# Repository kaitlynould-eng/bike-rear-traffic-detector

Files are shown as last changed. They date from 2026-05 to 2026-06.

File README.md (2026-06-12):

# bike-rear-traffic-detector

https://kaitlynould-eng.github.io/bike-rear-traffic-detector/

## Background

The purpose of this project is to assist a member of the team’s mom, Paula Ould. Paula was suddenly diagnosed in 2022 with a benign but hemorrhaging brain tumor. The tumor has since been successfully removed, but the process has limited her eyesight and degraded her motor function, rendering her legally unable to drive.
Since the surgeries, she has purchased an e-trike from RadPower to safely travel short distances from her house. She has added a mirror to increase her field of vision and a flag for visibility, among other modifications. She is able to ride safely in low-traffic environments, but is still nervous about biking on busier roads or at busier times of day because it is harder for her to detect objects at the very edge of her peripherals or behind her.
Therefore, our team’s goal is to create a system that detects and communicates the presence of rear oncoming traffic to Paula while she is on the road. This system is intended to act as an additional layer of information to support her existing safety measures, helping improve awareness and confidence, rather than encouraging riding in higher-risk conditions.

<div align="center">
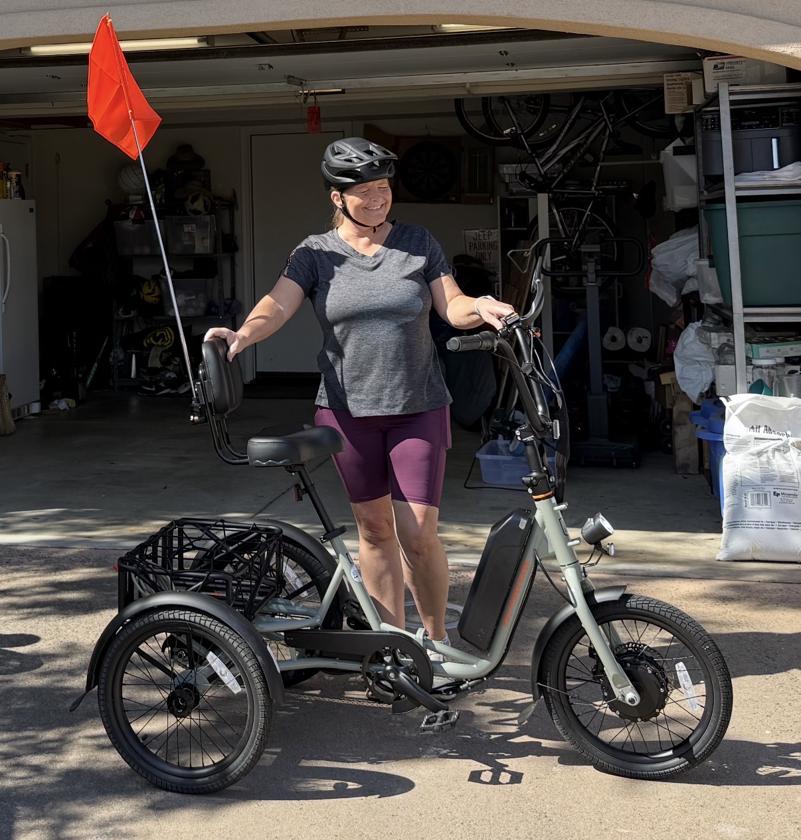
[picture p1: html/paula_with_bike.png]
    
    <br>
    <b>Figure 1:</b> User with RadPower E-trike.
</div>

## Introduction

Rear-facing bicycle safety and rider awareness system using mmWave radar, an STM32F411, and directional haptic feedback. Detects nearby vehicles in real time and alerts the rider through handlebar vibration motors using onboard radar and IMU sensor fusion.

# Hardware Design

## Overview

<div align="center">
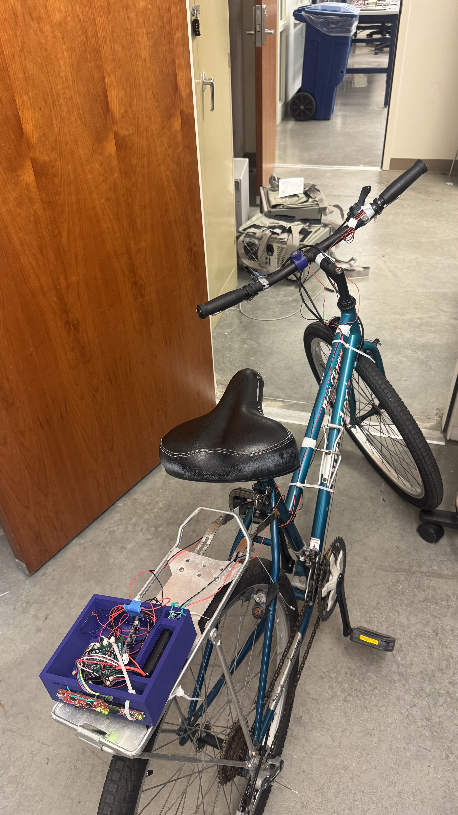
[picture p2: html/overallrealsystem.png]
    
    <br>
    <b>Figure 2:</b> Full prototype.
</div>

The hardware architecture of the rider-awareness system is centered around a custom printed circuit board that integrates sensing, processing, power regulation, and haptic feedback subsystems into a compact assembly suitable for bicycle use. The system is powered by a 2-cell lithium-ion battery pack and is designed to operate reliably in a vibration-prone outdoor environment through the use of connectorized wiring harnesses, regulated power distribution, and mechanically secured components.

A rear-facing TI IWR6843 mmWave radar module serves as the primary sensing device for detecting approaching vehicles and other rear hazards. An onboard BNO055 inertial measurement unit (IMU) provides orientation and motion data that allow the system to distinguish between riding and stationary conditions. Sensor data is processed by an STM32F411 microcontroller, which coordinates system operation and controls the rider notification subsystem.

Rider alerts are communicated through two handlebar-mounted vibration motors driven by dedicated DRV2605L haptic motor driver ICs. This haptic feedback approach was selected to provide intuitive notifications without requiring the rider to divert visual attention from the road or rely on audible alerts that may be masked by environmental noise.

All electronic components except for the motors are housed within a custom 3D-printed enclosure mounted to the rear cargo rack of a substitute bicycle. Paula’s e-trike was unavailable during testing, and so the prototype enclosure will be updated in the future to match the geometry of the intended vehicle. The enclosure incorporates dedicated mounting features and attachment points to securely retain the PCB, battery, radar module, and associated wiring. During prototype testing, the enclosure was secured to a substitute bicycle using zip ties attached to a rear basket rack, providing a simple and robust mounting solution without requiring permanent modifications to the bicycle. Internal cable management and connectorized harnesses were used to minimize strain on electrical connections and improve serviceability. Motors were mounted to the bike by being pressed into small, ring-like fixtures that snapped onto each handlebar.

<div align="center">
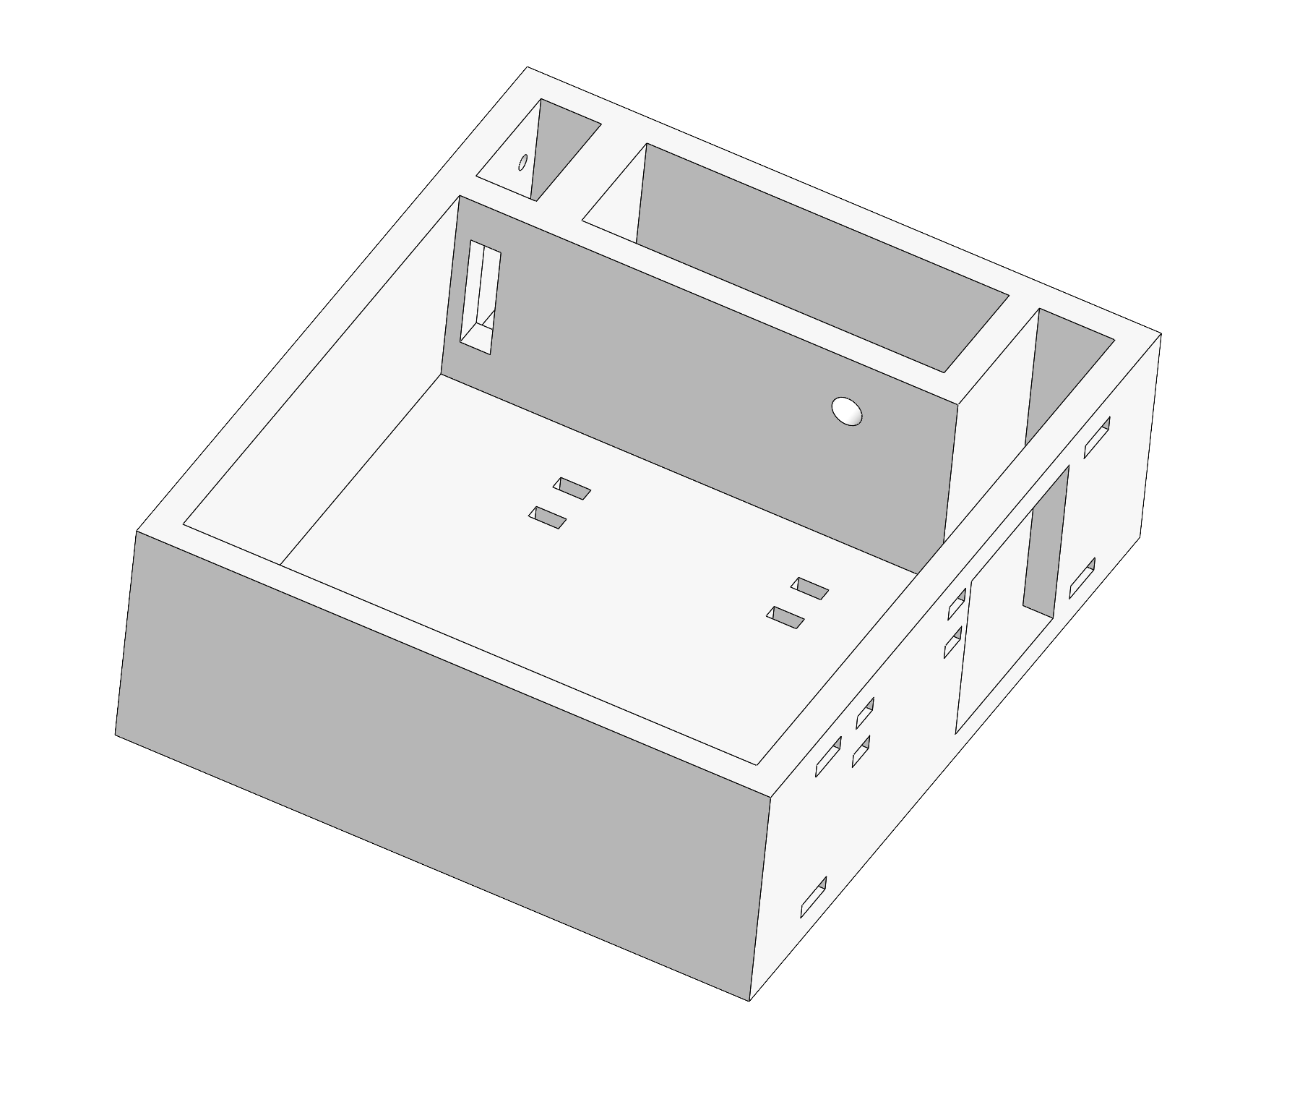
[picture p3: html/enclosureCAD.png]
    
    <br>
    <b>Figure 3:</b> Enclosure design.
</div>
<div align="center">
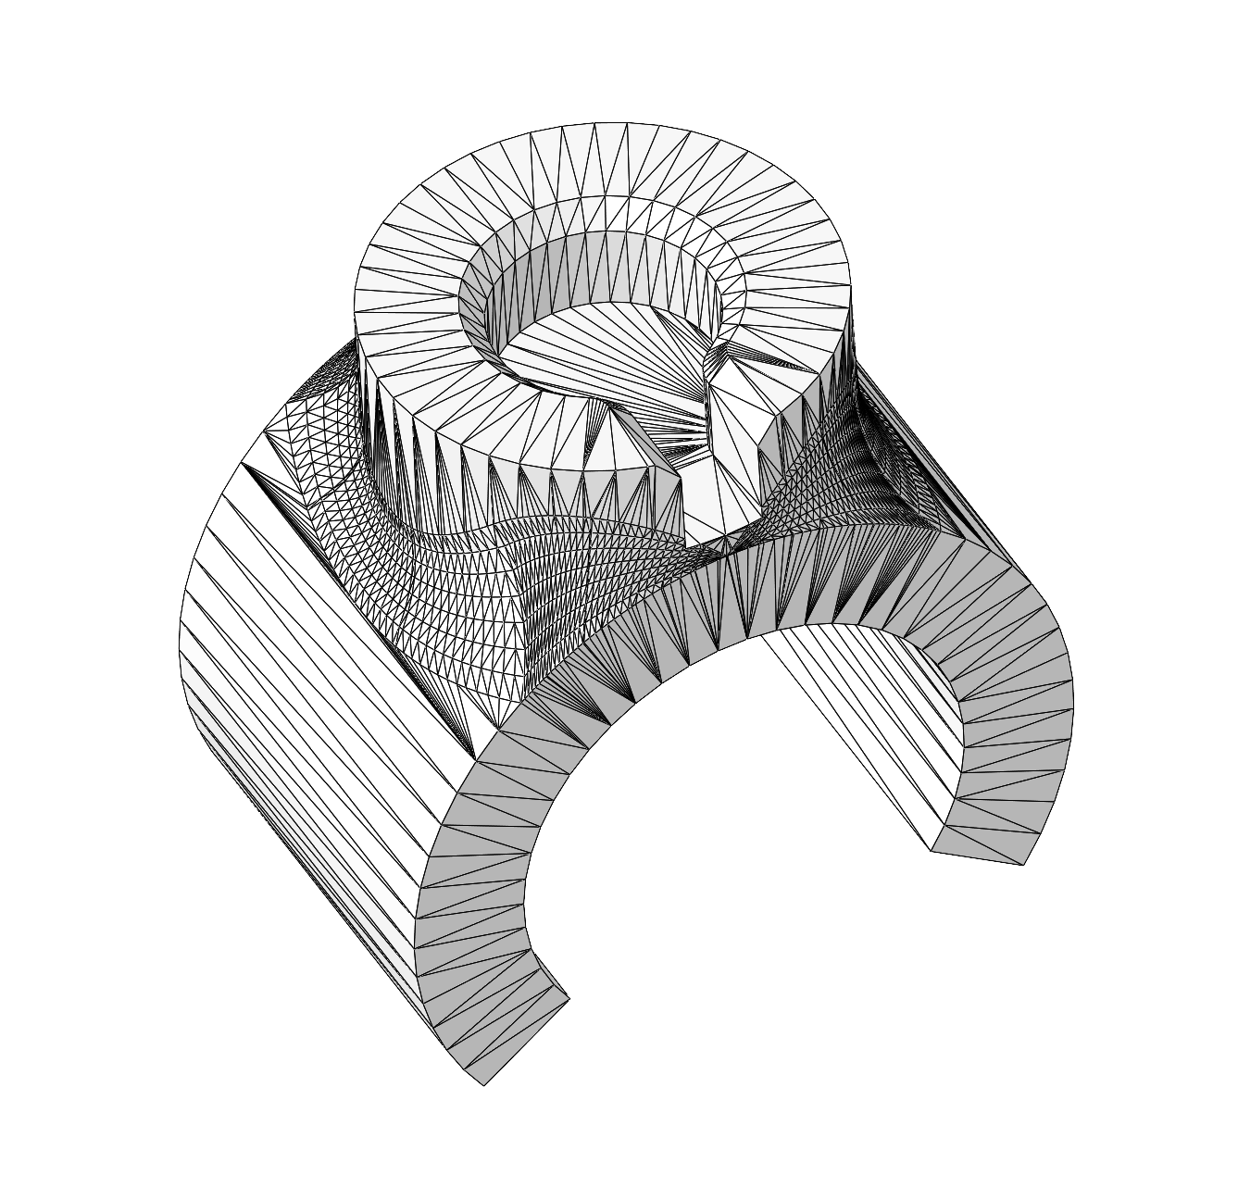
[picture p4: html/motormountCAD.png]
    
    <br>
    <b>Figure 4:</b> Motor mount design.
</div>

The hardware is organized into six primary subsystems: power distribution, radar sensing, inertial measurement, haptic feedback, programming and debug interfaces, and wiring and harnessing. The following sections describe the design considerations and implementation details of each subsystem.

## Power Distribution

The power distribution system is responsible for converting and regulating battery power for all sensing, processing, and feedback electronics within the rider-awareness system. Power is supplied by a 2-cell lithium-ion battery pack with a nominal voltage of 7.4 V. Battery power enters the PCB through a connectorized interface and first passes through a 2 A resettable PTC fuse to provide overcurrent protection. A P-channel MOSFET configured for reverse-polarity protection prevents damage to the electronics if the battery is connected incorrectly.

<div align="center">
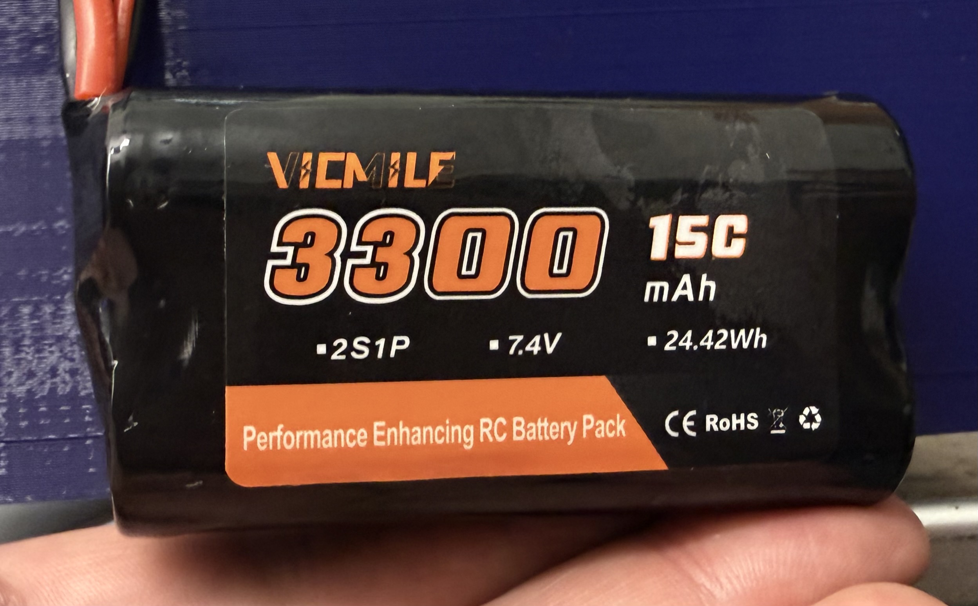
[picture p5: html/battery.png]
    
    <br>
    <b>Figure 5:</b> 2S Li-ion Battery.
</div>

Following the protection circuitry, battery voltage is regulated by a TPS542025 switching buck converter configured to generate a 5 V power rail. A switching regulator was selected instead of a linear regulator to improve efficiency and reduce heat dissipation, which is especially important for a battery-powered system. The 5 V rail directly powers the TI IWR6843 mmWave radar module and serves as the input to the secondary voltage regulation stage.

A NCP1117 low-dropout linear regulator generates a regulated 3.3 V rail from the 5 V supply. This rail powers all low-voltage digital electronics, including the STM32F411 microcontroller, BNO055 inertial measurement unit, and both DRV2605L haptic motor driver ICs. The use of a dedicated LDO provides a clean and stable supply for the digital and sensing subsystems while maintaining compatibility with the operating voltage requirements of these devices.

To maintain power integrity throughout the system, bulk capacitance is placed at the outputs of both regulators, while local decoupling capacitors are located near integrated circuits and connector interfaces. These capacitors help suppress voltage transients, reduce switching noise, and ensure stable operation during dynamic load conditions such as radar operation and vibration motor actuation.

Current consumption estimates indicate a steady-state 3.3 V load of approximately 202 mA, increasing to approximately 282 mA during vibration motor startup. The selected power architecture provides sufficient current capacity for all system components while maintaining efficient operation and protecting the electronics from common power-related faults.

<div align="center">
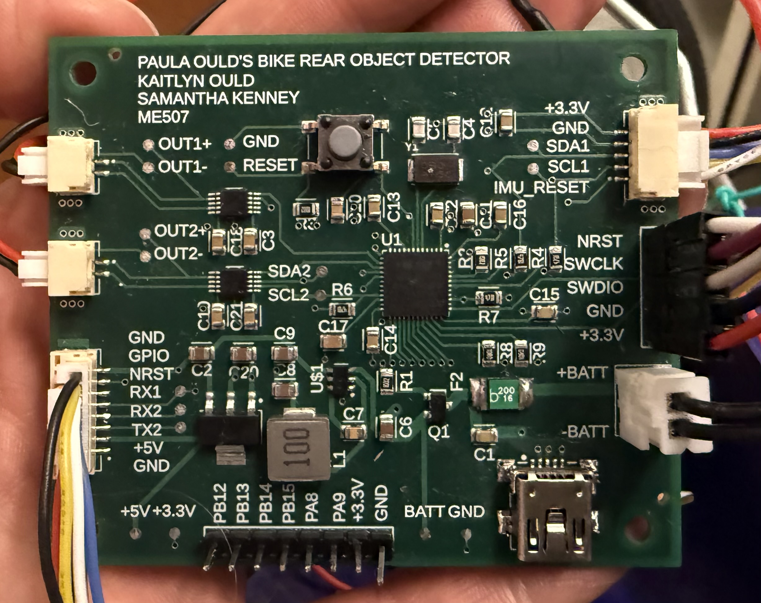
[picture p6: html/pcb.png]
    
    <br>
    <b>Figure 6:</b> System PCB.
</div>

## Radar Sensor

Rear traffic detection is performed using a Texas Instruments IWR6843 mmWave radar module mounted at the rear of the bicycle enclosure. The radar operates in the 60 GHz frequency band and was selected for its ability to reliably detect and track moving objects under a wide range of environmental conditions. Unlike optical sensors or cameras, mmWave radar performance is largely unaffected by lighting conditions, shadows, glare, or moderate weather effects, making it well suited for bicycle safety applications.

<div align="center">
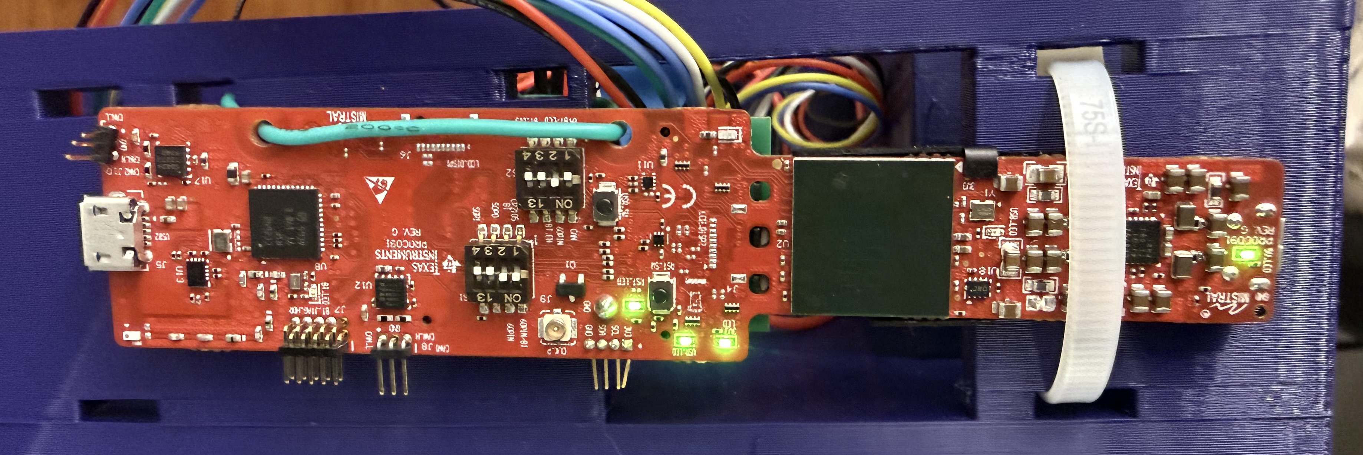
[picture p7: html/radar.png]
    
    <br>
    <b>Figure 7:</b> Radar module mounted to enclosure for testing.
</div>

The radar module is powered from the regulated 5 V rail generated by the onboard power distribution system. Communication between the radar and the STM32F411 microcontroller is accomplished through dedicated UART interfaces. One UART connection is used for radar configuration and initialization, while a second UART interface is used to transmit processed target detection data to the microcontroller. Additional reset and GPIO signals are routed through the radar connector to support system control and status monitoring. The radar is connected to the PCB through a locking JST-GH harness to improve reliability in the vibration-prone bicycle environment.

The radar is mounted within the rear enclosure and oriented to monitor traffic approaching from behind the rider. By continuously measuring target range, velocity, and relative motion, the sensor provides the primary situational-awareness input for the system. These measurements enable the rider-awareness system to identify approaching vehicles and generate appropriate haptic notifications through the handlebar vibration motors.

The IWR6843 was selected because it combines a compact form factor with integrated signal processing capabilities and sufficient detection range for bicycle applications. Its ability to provide direct velocity measurements through Doppler processing is particularly valuable for distinguishing approaching vehicles from stationary roadside objects, reducing false detections and improving the relevance of rider alerts.

## Inertial Measurement Unit

System motion and orientation are measured using a Bosch BNO055 inertial measurement unit (IMU). The BNO055 was selected because it integrates a 3-axis accelerometer, 3-axis gyroscope, and 3-axis magnetometer into a single package while also providing onboard sensor fusion. This reduces computational requirements on the STM32F411 microcontroller and simplifies the implementation of orientation and motion tracking.

The IMU operates from the regulated 3.3 V power rail and communicates with the STM32F411 over an I²C interface. In addition to power, ground, and communication signals, a dedicated reset line is routed between the microcontroller and IMU to allow software-controlled reinitialization if necessary. The sensor is connected to the PCB through a locking JST-GH connector and wiring harness to ensure reliable operation in the vibration-prone bicycle environment.

The primary purpose of the IMU is to determine whether the bicycle is in motion and to provide orientation information that can be used to improve system awareness. This information allows the system to differentiate between riding and stationary conditions, enabling different notification behaviors depending on the rider’s state. For example, approaching traffic while the bicycle is moving generates continuous haptic feedback, whereas approaching traffic while stopped generates a brief notification alert.

The BNO055 was selected due to its integrated sensor-fusion capabilities, ease of implementation, and proven reliability in embedded motion-sensing applications. By providing stable orientation and acceleration data, the IMU serves as an important secondary sensing subsystem that complements the radar-based traffic detection system and improves the overall contextual awareness of the device.

## Haptic Feedback System

Rider notifications are communicated through a dual-channel haptic feedback system consisting of two vibration motors mounted within the bicycle handlebars. Haptic feedback was selected as the primary alert method because it provides immediate and intuitive notifications without requiring the rider to divert visual attention from the road or rely on audible signals that may be masked by traffic noise or environmental conditions.

Each vibration motor is controlled by a dedicated Texas Instruments DRV2605L haptic motor driver IC. The DRV2605L devices operate from the regulated 3.3 V power rail and communicate with the STM32F411 microcontroller over an I²C interface. Using dedicated driver ICs eliminates the need for the microcontroller to directly drive the motors and provides consistent vibration performance while reducing electrical stress on the control electronics. The motors are connected to the PCB through locking JST-GH connectors and dedicated wiring harnesses designed to withstand the vibration and movement encountered during bicycle operation.

The haptic feedback subsystem converts processed radar and motion-sensing information into tactile alerts that can be easily interpreted by the rider. When the bicycle is moving and rear traffic is detected, the vibration motors generate alerts whose intensity varies according to the relative speed of the approaching object. This allows the rider to receive information about nearby traffic without the need to monitor a display or listen for audio cues. When the bicycle is stationary, the system instead provides a brief notification vibration to indicate the presence of approaching rear traffic.

The vibration motors are housed within dedicated 3D-printed handlebar mounts positioned near the rider's hands to maximize perceptibility and ensure alerts can be detected even in noisy outdoor environments. By providing a direct tactile communication method, the haptic feedback subsystem serves as the primary interface between the rider-awareness system and the user.

<div align="center">
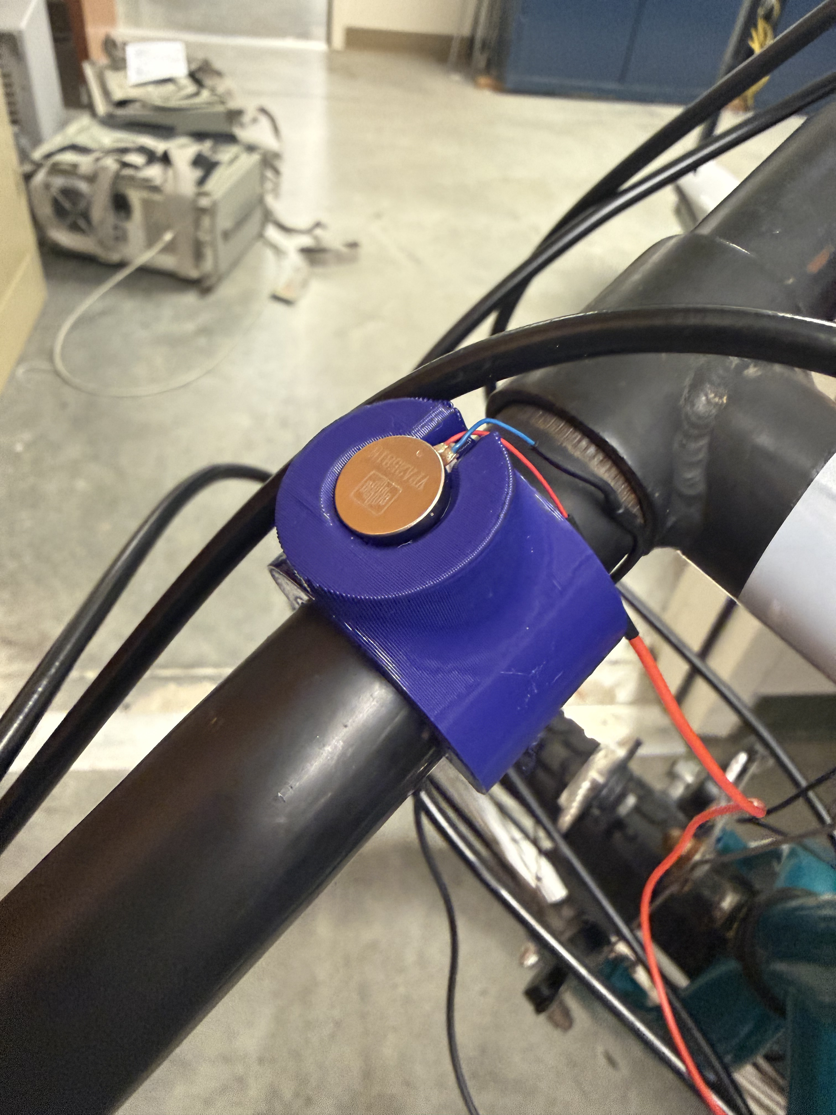
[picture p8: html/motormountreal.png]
    
    <br>
    <b>Figure 8:</b> Motors mounted in 3D printed attachment.
</div>

## Communications and Debug Interfaces

The rider-awareness system incorporates dedicated communication and debugging interfaces to support firmware development, testing, and troubleshooting. These interfaces provide access to the STM32F411 microcontroller for programming, debugging, and system monitoring throughout development.

A Serial Wire Debug (SWD) header is included on the PCB to allow programming and real-time debugging of the STM32F411 microcontroller using an ST-Link debugger. The interface exposes the SWDIO, SWCLK, NRST, 3.3 V, and ground signals required for firmware upload, breakpoint debugging, memory inspection, and device recovery. This interface was used throughout development to validate sensor communication, test control algorithms, and diagnose hardware issues.

In addition to the SWD interface, the PCB includes a USB Mini-B connector that provides a direct connection between the microcontroller and a host computer. The USB interface enables serial communication through a virtual COM port, allowing sensor data, diagnostic information, and system status messages to be monitored during testing and development. This connection simplifies system validation by providing a convenient method for observing device behavior and recording system outputs during operation.

Together, the SWD and USB interfaces provide the primary tools used for firmware deployment, debugging, data collection, and system verification. Including both interfaces improved development efficiency and enabled thorough testing of the sensing, processing, and haptic feedback subsystems throughout the project lifecycle.

## Wiring and Harnessing

The rider-awareness system utilizes a connectorized wiring architecture to distribute power and communication signals between the PCB and external subsystems. Because the system is intended for operation on a bicycle, wiring reliability and resistance to vibration were important design considerations throughout the development process. Connectorized harnesses simplify assembly, maintenance, and troubleshooting while reducing the likelihood of intermittent electrical connections caused by cable movement or vibration.

Power is delivered from the battery pack to the PCB through dedicated high-current wiring sized to support the system load with minimal voltage drop. Lower-current sensor and communication connections use smaller-gauge wiring to reduce overall cable bulk and improve routing flexibility within the enclosure and along the bicycle frame. Wire gauges and connector selections were chosen based on expected current requirements, mechanical robustness, and ease of assembly.
The design incorporates several connector families, including XT30, JST-XH, JST-GH, and standard header interfaces. Locking JST-GH connectors were selected for sensor and motor connections because they provide secure retention and are well suited for environments subject to vibration and movement. These connectors also allow subsystems to be disconnected individually for testing, replacement, or maintenance without requiring modification to the wiring harness.

<div align="center">
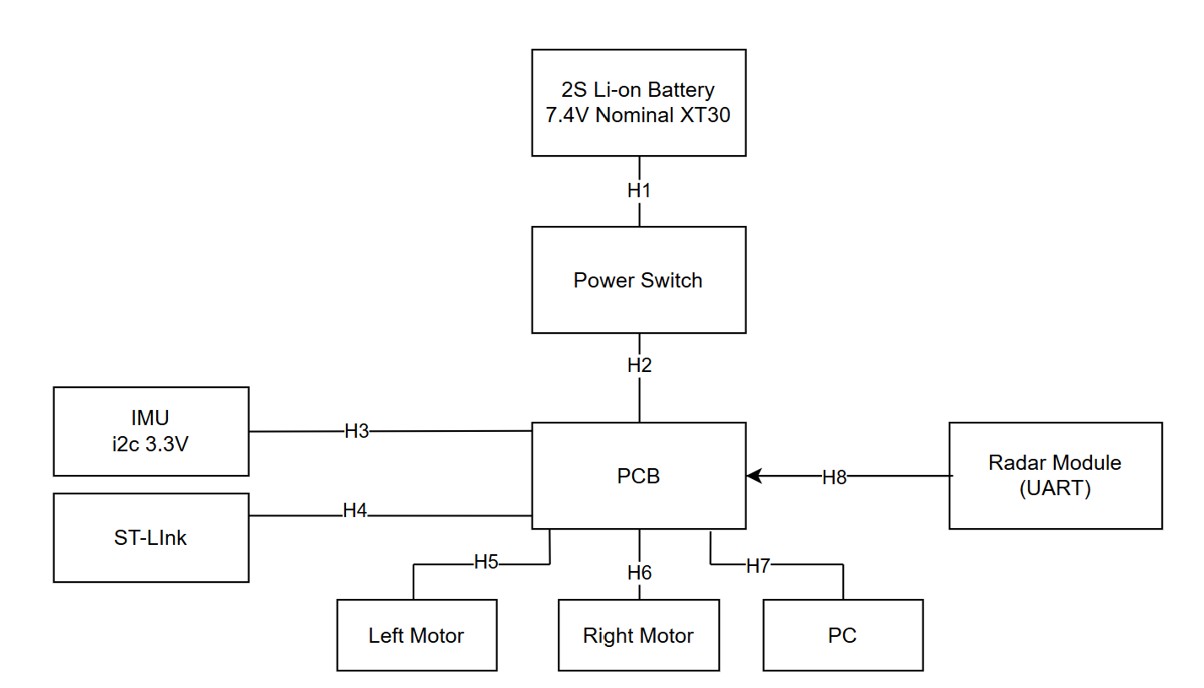
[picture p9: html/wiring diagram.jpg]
    
    <br>
    <b>Figure 9:</b> Wiring Diagram.
</div>

The wiring architecture is divided into eight primary harnesses that connect the battery, power switch, radar module, inertial measurement unit, vibration motors, USB interface, and debugging hardware to the main control board. Each harness is documented with connector types, wire gauges, and signal assignments to support manufacturing, assembly, and future maintenance activities.

Careful attention was given to harness routing within the enclosure and along the bicycle structure to minimize cable strain, prevent interference with moving components, and reduce excess wire length. Connector placement on the PCB was coordinated with enclosure layout to simplify assembly and improve serviceability. During prototype testing, harnesses were secured using cable management features and routing paths designed to prevent entanglement while maintaining access to critical system components.

Detailed harness documentation, including signal definitions, connector pinouts, wire gauges, and routing information for each cable assembly, is provided in the subsequent figures and tables.

# Major Software

## Radar System Development

The radar subsystem is built around the Texas Instruments IWR6843AOP mmWave radar sensor, which serves as the primary environmental sensing device for the project. The radar was selected because it can directly measure target motion using Doppler velocity information while remaining compact enough for integration into a wearable system. Unlike traditional proximity sensors, the radar can distinguish moving objects and provide velocity measurements, allowing the system to respond differently depending on how quickly a target is approaching.

## Hardware configuration

Before software development could begin, the IWR6843AOP radar evaluation module required several hardware configuration changes to enable communication with the custom STM32-based PCB. The UART routing and operating mode switches on the radar evaluation board were configured to allow direct communication between the radar and the microcontroller. This enabled the radar to operate independently of a host PC during normal operation while still allowing access to the radar's command-line interface for configuration and testing.

The switch positions used throughout development are shown below:
<div align="center">
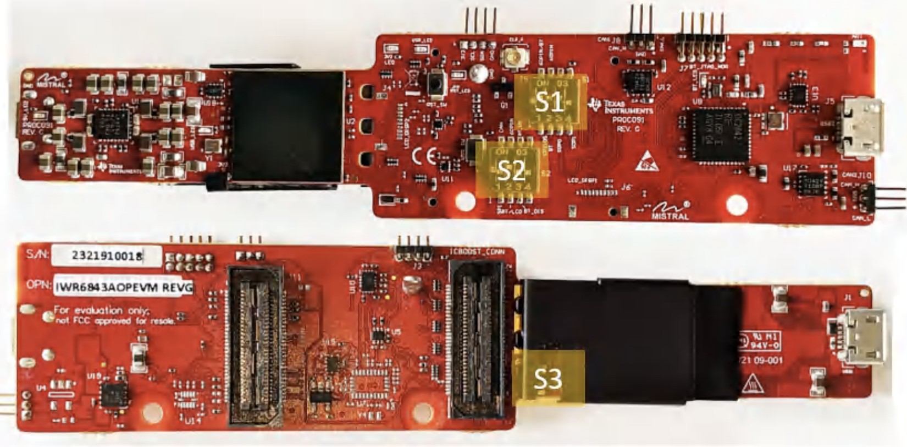
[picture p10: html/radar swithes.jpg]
    
    <br>
    <b>Figure 10:</b> IWR6843AOP Evaluation Module switch locations used during development.
</div>

 Table 1. Switch configuration
| Switch | Position |
|---|---|
| S1.1 | ON |
| S1.2 | ON |
| S1.3 | ON |
| S1.4 | OFF |
| S2.1 | OFF |
| S2.2 | ON |
| S2.3 | OFF |
| S2.4 | OFF |
| S3 | OFF | 

These settings configured the radar module for UART communication with the STM32 and were required before software testing and radar configuration development could begin.

The radar communicates with the STM32 through two UART interfaces. A 115200 baud Command Line Interface (CLI) UART is used to transmit configuration commands to the radar, while a separate 921600 baud data UART is used to receive real-time object detection data. This dual-UART architecture separates radar configuration traffic from high-speed sensor data, ensuring reliable communication during operation. The CLI UART is used only during initialization and configuration, while the high-speed data UART continuously streams radar detection packets during normal operation.

## Configuration Development and Testing

A significant portion of the radar development process involved determining an appropriate configuration for the application. Texas Instruments provides a large number of configurable radar parameters that influence range resolution, velocity resolution, frame rate, transmit power, and target detection performance.

To evaluate these parameters, the TI mmWave Demo Visualizer software was used extensively during development. This software provides real-time displays of radar point clouds, detected objects, and Doppler velocity information, allowing different configurations to be tested and compared quickly. Multiple configurations were evaluated to determine which settings provided the most reliable detection of approaching targets while minimizing false detections and unnecessary processing overhead.

Particular attention was given to Doppler measurements because the project relies on detecting approaching motion rather than generating a detailed environmental map. By observing velocity data within the Demo Visualizer, threshold values and radar operating parameters were tuned to provide stable and repeatable motion classification for the wearable warning system.

Once a suitable configuration was identified, the resulting command sequence was incorporated directly into the STM32 firmware. During startup, the radar driver automatically transmits the complete configuration to the radar module, eliminating the need for a separate configuration utility during normal operation.

## Drivers
All drivers developed for this project can be found within the Core folder of the repository. This section provides an overview of the custom drivers and application code created to support the bicycle safety system. Four primary modules were developed and modified throughout the project: the Radar, Haptic, IMU, and Main modules. Together, these files form the foundation of the embedded software architecture and enable communication between the hardware components while implementing the system's overall functionality. The following subsections describe the purpose, implementation, and key features of each module.
## Radar module information
One of the most important software components of the project is the custom radar driver developed for the IWR6843AOP sensor. The driver abstracts the complexity of radar communication and packet processing, providing the rest of the application with simple motion-detection states.

During initialization, the driver transmits the complete radar configuration over the CLI UART and prints the radar responses to the USB debugging interface. This allows configuration progress and communication status to be monitored during development and testing. Once configured, the driver continuously receives binary data packets from the radar over the high-speed data UART.

The incoming byte stream is searched for the Texas Instruments radar packet magic word, which marks the beginning of a valid radar frame. The driver then parses the packet header and iterates through the packet's Type-Length-Value (TLV) structures to locate detected-point data. Doppler velocity measurements are extracted from each detected point and analyzed to determine the maximum observed target velocity within the frame.

For this project, only negative Doppler values are considered because they correspond to objects moving toward the radar sensor. The driver identifies the fastest approaching object and classifies the result into three application-level states:

RADAR_NO_OBJECT – No approaching object detected above the minimum velocity threshold.
RADAR_YIPPEE_1 – An approaching object detected with a velocity between approximately 0.05 m/s and 3.129 m/s.
RADAR_YIPPEE_2 – An approaching object detected with a velocity greater than 3.129 m/s.

This approach greatly simplifies the rest of the software architecture by converting complex radar point
## Haptic Driver
The haptic driver provides a clean interface for controlling the two DRV2605 haptic motor drivers used in the wearable feedback system. The driver handles all low-level I2C communication and motor initialization, including configuring both DRV2605 devices for Real-Time Playback (RTP) mode. This allows vibration intensity to be controlled directly through software. Higher-level functions such as Haptic_PlayForMs(), Haptic_Off(), and Haptic_LongWarningPattern() allow the main application to generate feedback without needing to interact with device registers or communication protocols.

Different feedback patterns are created by varying vibration intensity, pulse duration, and timing. The Haptic_PlayForMs() function generates a continuous vibration for a specified duration, while Haptic_LongWarningPattern() creates a multi-pulse warning consisting of two short vibration bursts followed by a longer pulse. By encapsulating all hardware-specific details within the driver, the haptic subsystem remains modular, reusable, and easy to integrate with the radar and IMU sensing systems.

## IMU Driver
The IMU driver is written in C using STM32 HAL and communicates with a BNO055 sensor over I2C. The driver begins by defining the BNO055 I2C address and the internal register addresses needed to configure and read from the sensor. During IMU_Init(), the driver stores the I2C handle, waits for the BNO055 to boot, places the sensor into configuration mode, sets the power mode and unit selection, and then switches the sensor into AMG mode. AMG mode enables accelerometer, magnetometer, and gyroscope operation.

The main function in the driver is IMU_Update(). This function reads six bytes of linear acceleration data from the BNO055, corresponding to the X, Y, and Z acceleration axes. The raw sensor values are converted into acceleration values in meters per second squared by dividing by 100. These values are stored as the most recent acceleration readings so that other parts of the program can access them later.

After reading the acceleration data, the driver calculates the total acceleration magnitude using the X, Y, and Z components. This magnitude is compared to a motion threshold of 0.25 m/s². If the acceleration magnitude is above this threshold, the driver considers the device to be moving and updates last_motion_time. If the acceleration stays below the threshold for at least 15 seconds, the driver returns IMU_STOPPED.

## Main Loop and System Intelligence
The intelligence of the system is implemented through an event-driven main loop that combines information from both the radar and IMU subsystems. During each iteration, the radar driver processes incoming Doppler measurements and classifies nearby motion as either moderate motion, fast motion, or no detection. At the same time, the IMU driver evaluates the bike's motion state and determines whether the device has remained stable for an extended period.

The main application uses information from both sensors to select an appropriate haptic response. When a radar detection occurs while the IMU indicates normal movement, the system generates a continuous vibration warning. If the radar detects motion while the IMU reports that the device has remained stable for an extended period, a more noticeable multi-pulse warning pattern is generated. This allows the system to provide context-aware feedback rather than responding solely to radar detections.

## Overview of the main loop

The main control loop continuously receives processed radar data over the I²C interface and evaluates the motion of nearby objects relative to the user. The software extracts the Doppler velocity information from detected targets and determines whether an object is approaching. The magnitude of the approach speed is then mapped to a corresponding vibration intensity for the handlebar-mounted haptic motors. Faster approaching objects produce stronger vibrations, allowing the user to quickly assess the severity of a potential hazard without diverting attention from the road. This approach transforms raw radar measurements into intuitive feedback, enabling the system to communicate both the presence and urgency of nearby objects in real time. The continuous execution of this loop allows the device to adapt immediately to changing traffic conditions and provide responsive warnings to the user.
## Coding Style and Software Architecture
The project is implemented in embedded C using the STM32 HAL framework. The software follows a modular driver-based architecture in which each hardware subsystem—including the radar, IMU, haptic motors, and USB communication interface—is isolated within its own source and header files. This organization improves code readability, simplifies debugging, and allows individual components to be modified without affecting the rest of the system.

Although the project does not use object-oriented programming or a real-time operating system, it incorporates many object-oriented design principles such as abstraction and encapsulation. Hardware-specific details are hidden inside each driver, exposing only simple public interfaces to the application layer. The overall system operates using an event-driven polling loop, where sensor inputs are continuously evaluated and used to determine the appropriate system response. This lightweight architecture is well suited for real-time embedded applications while remaining easy to understand and maintain.

# Testing

<div align="center">
    <video width="800" controls>
        <source src="demo.mp4" type="video/mp4">
        Your browser does not support the video tag.
    </video>
    <br>
    <b>Video 1:</b> Final Project Demonstration.
</div>

NOTE: If the video does not embed properly in your browser, please download demo.mp4 in the github repo to view the final testing.

## USB Debugging Interface

To simplify development and testing, the custom PCB includes a USB connection that enables direct communication between the STM32 microcontroller and a host computer. The project uses the STM32 USB CDC (Communications Device Class) interface to create a virtual serial port that can be accessed through terminal software such as PuTTY.

A custom debug_print() function was implemented to transmit diagnostic messages over USB. Throughout development, this interface was used to monitor radar detections, verify IMU operation, confirm successful peripheral initialization, and observe the system's decision-making logic in real time. This capability significantly reduced debugging time by providing immediate visibility into the internal state of the system without requiring additional hardware debugging tools.

The USB debugging interface was particularly valuable during integration testing, allowing rapid verification that the radar, IMU, and haptic subsystems were communicating correctly and producing the expected responses under different operating conditions.

## Bike Testing
The testing process began with the bicycle stationary to verify that the radar module could reliably detect approaching objects and trigger the appropriate haptic warnings. During these initial tests, both YIPPEE 1 and YIPPEE 2 activated as expected, demonstrating that the radar and warning system were functioning correctly. However, when testing was expanded to include a moving bicycle, the radar began detecting environmental objects such as bushes, resulting in unwanted activations. To address this issue, the detection range was modified to only consider objects between 1 m and 8.92 m from the bicycle. This adjustment significantly improved performance by filtering out very close detections while still providing adequate warning distance for approaching hazards. Additionally, a minimum velocity threshold of 0.1 m/s was implemented to reduce false detections caused by moving bushes or tree branches in windy conditions. Based on feedback from Paula regarding the level of warning she desired under different situations, the velocity ranges for the two warning modes were refined. YIPPEE 1 was configured to activate for approaching objects with velocities between 0.1 m/s and 2.2 m/s, representing lower-speed hazards such as pedestrians walking toward the cyclist. YIPPEE 2 was configured to activate for velocities greater than 2.2 m/s, representing faster-moving hazards that require increased awareness. The design goal was to detect approaching hazards at distances up to 8.92 m. During validation testing, objects approaching directly behind the bicycle were detected at nearly the full 8.92 m range. However, when objects approached from the left or right side of the radar field of view, detection typically occurred at approximately 6 m, which is consistent with the reduced sensitivity at the edges of the radar's detection zone. The haptic feedback system was also evaluated to verify proper integration with the IMU. When the bicycle was stationary, the system correctly activated the patterned warning vibration, indicating that the IMU detected a stable bicycle state. When the bicycle was in motion, the system successfully switched to the continuous long-buzz warning mode, demonstrating that the IMU correctly identified bicycle movement and altered the haptic feedback accordingly. This behavior confirms that the IMU-based state detection functioned as intended and provided context-appropriate warnings to the rider. As shown in Table X, YIPPEE 1 consistently activated when a person approached while walking, while YIPPEE 2 activated when a person approached on a skateboard. These results demonstrate that the system can distinguish between different levels of approaching hazards and provide an appropriate warning to the rider while minimizing false detections from surrounding environmental features.

                                                               Table 2. Testing Results
| Trial | Approach Direction | Distance (m) | Bike Stationary | YIPPEE 1 Activated | YIPPEE 2 Activated | Bike Moving | YIPPEE 1 Activated | YIPPEE 2 Activated |
|---|---|---|---|---|---|---|---|---|
| 1 | Left | <8.92 | Yes | Yes | Yes | Yes | Yes | Yes |
| 2 | Center | <8.92 | Yes | Yes | Yes | Yes | Yes | Yes |
| 3 | Right | <8.92 | Yes | Yes | Yes | Yes | Yes | Yes |

# Challenges & Lessons Learned

## Radar Configuration and Software Integration

One of the most significant challenges involved the TI IWR6843 mmWave radar module. Unlike many sensors that function immediately after wiring and power-up, the radar required separate configuration through Texas Instruments software tools before it could begin transmitting useful data. This process was complicated by documentation inconsistencies and software version compatibility issues, as some referenced tools and resources were outdated. Significant time was spent identifying the correct software environment and configuration procedure before successful communication could be established. While the IWR6843 ultimately simplified system development by providing onboard target detection and processing, integrating the module required considerably more software configuration than initially anticipated. This highlighted the importance of evaluating not only sensor capabilities, but also the supporting software ecosystem, configuration procedures, and development tools associated with highly integrated hardware platforms.

## Radar Communication and Hardware Interface Challenges

Establishing communication with the radar module proved more difficult than initially anticipated. Early testing indicated that the radar was powered correctly but was not transmitting usable data to the microcontroller. After extensive debugging, the team determined that the radar's hardware configuration switches and communication routing were not configured correctly. The system only began functioning once the appropriate communication path was routed from the PC USB connection through the radar's onboard interface and into the UART channels used by the microcontroller.

Additional challenges arose from the radar connector itself. During the initial PCB design, it was assumed that the exposed header pins on the radar module provided access to the required communication signals. Later investigation revealed that the necessary interfaces were only available through the radar's J2 60-pin connector. Because this connector was incompatible with the existing PCB design and difficult to interface with directly, the team designed and manufactured a custom adapter PCB that broke out the required signals from the 60-pin connector to a JST-GH connector compatible with the main control board. This redesign required additional effort and cost but ultimately was able to cleanly interface between the two boards. See f3z files for full electronics designs.

## Detection Threshold Tuning

While the radar was capable of reliably detecting objects, determining appropriate detection thresholds required substantial experimentation. Multiple rounds of testing were performed to tune velocity and distance thresholds for the intended bicycle environment. Thresholds that were too sensitive resulted in unnecessary detections, while overly restrictive settings reduced warning time and awareness for approaching vehicles. Through iterative testing and refinement, the team identified operating parameters that provided reliable detection performance while minimizing false alerts. This process demonstrated the importance of real-world testing when developing sensor-based systems.

## Power Management and Demonstration Readiness

A final challenge occurred immediately prior to the project demonstration when the primary battery pack had discharged to approximately 6.2 V. The reduced battery voltage resulted in unreliable system operation and required the team to quickly recharge the battery and prepare a backup power source shortly before the demonstration. Although the issue was resolved successfully, it emphasized the importance of power-management planning, battery monitoring, and pre-demonstration system checks.

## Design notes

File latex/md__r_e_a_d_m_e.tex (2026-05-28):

\chapter{bike-\/rear-\/traffic-\/detector }
\hypertarget{md__r_e_a_d_m_e}{}\label{md__r_e_a_d_m_e}\index{bike-\/rear-\/traffic-\/detector@{bike-\/rear-\/traffic-\/detector}}
\label{md__r_e_a_d_m_e_autotoc_md0}%
\Hypertarget{md__r_e_a_d_m_e_autotoc_md0}%

Rear-\/facing bicycle safety and rider awareness system using mm\+Wave radar, an STM32\+F411, and directional haptic feedback. Detects nearby vehicles in real time and alerts the rider through handlebar vibration motors using onboard radar and IMU sensor fusion.

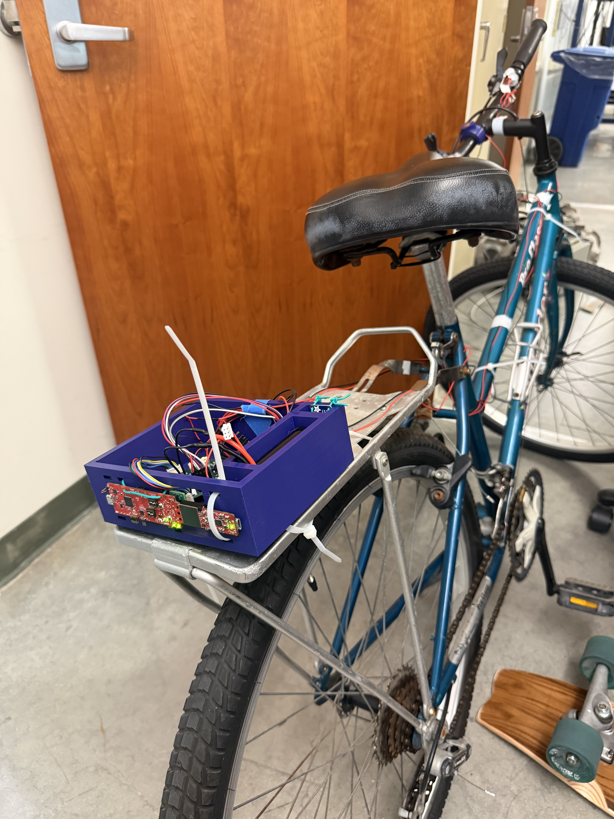
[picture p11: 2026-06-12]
html/overallrealsystem_close.png

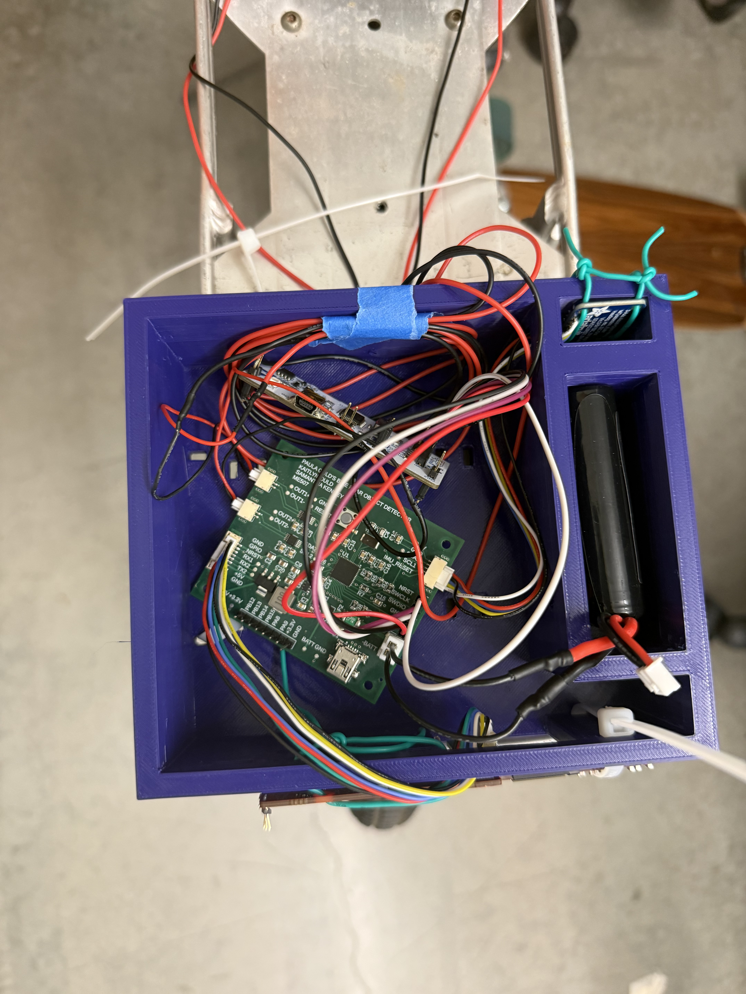
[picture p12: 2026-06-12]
html/actualenclosuretopview.png

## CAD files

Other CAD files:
60PinAdapter_ElectronicsDesign.f3z
RiderAwarenessSystem_ElectronicsDesign.f3z

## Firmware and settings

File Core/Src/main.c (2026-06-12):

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
/* Includes ------------------------------------------------------------------*/
#include "main.h"
#include "usb_device.h"
#include "usbd_cdc_if.h"
#include "radar.h"
#include <string.h>
#include "haptic.h"
#include "imu.h"
I2C_HandleTypeDef hi2c1;
I2C_HandleTypeDef hi2c2;

UART_HandleTypeDef huart1;
UART_HandleTypeDef huart2;

void SystemClock_Config(void);
static void MX_GPIO_Init(void);
static void MX_USART2_UART_Init(void);
static void MX_I2C1_Init(void);
static void MX_I2C2_Init(void);
static void MX_USART1_UART_Init(void);
/* USER CODE BEGIN 0 */
//#define DRV2605_ADDR     (0x5A << 1)
//#define DRV2605_REG_MODE 0x01
//#define DRV2605_REG_RTP  0x02

void debug_print(char *msg)
{
	 CDC_Transmit_FS((uint8_t *)msg, strlen(msg));
}


/* USER CODE END 0 */

/**
  * @brief  The application entry point.
  * @retval int
  */
int main(void)
{

  /* MCU Configuration--------------------------------------------------------*/

  /* Reset of all peripherals, Initializes the Flash interface and the Systick. */
  HAL_Init();

  /* Configure the system clock */
  SystemClock_Config();

  /* Initialize all configured peripherals */
  MX_GPIO_Init();
  MX_USART2_UART_Init();
  MX_I2C1_Init();
  MX_I2C2_Init();
  MX_USART1_UART_Init();
  MX_USB_DEVICE_Init();
  HAL_Delay(3000);
  /* USER CODE BEGIN 2 */
  debug_print("STM32 started\r\n");
  HAL_GPIO_WritePin(GPIOA, EN1_Pin, GPIO_PIN_SET);
  HAL_GPIO_WritePin(GPIOA, EN2_Pin, GPIO_PIN_SET);
  HAL_Delay(10);
  Haptic_Init(&hi2c1, &hi2c2);
  HAL_GPIO_WritePin(GPIOA, BNO055_RST_Pin, GPIO_PIN_SET);
  HAL_Delay(700);
  IMU_Init(&hi2c1);
  Radar_Init(&huart2, &huart1);
  Radar_SendConfig();
  /* IMU test after radar config */

  IMU_Update();

//  uint8_t test_byte;
//  HAL_Delay(500);
//  debug_print("CHECKPOINT A\r\n");
//  HAL_Delay(500);
//
//  if (HAL_UART_Receive(&huart1, &test_byte, 1, 2000) == HAL_OK)
//  {
//      debug_print("FIRST DATA BYTE RECEIVED\r\n");
//  }
//  else
//  {
//      debug_print("NO FIRST DATA BYTE\r\n");
//  }
//  debug_print("Testing motors\r\n");
////  Haptic_Yippee1();
//  HAL_Delay(1000);
//  Haptic_Off();
//  debug_print("Motor test done\r\n");
  /* USER CODE END 2 */

  /* Infinite loop */
  /* USER CODE BEGIN WHILE */
  while (1)
  {
      static uint8_t last_stable_state = 255;

      RadarResult_t radar_state = Radar_Update();

      IMU_Update();
      uint8_t ax_stable = IMU_AxStableFor10s();

      // Print only when stability changes
      if (ax_stable != last_stable_state)
      {
          if (ax_stable)
          {
              debug_print("IMU STABLE\r\n");
          }
          else
          {
              debug_print("IMU NOT STABLE\r\n");
          }

          last_stable_state = ax_stable;
      }

      if (radar_state == RADAR_YIPPEE_1)
      {
          debug_print("YIPPEE 1\r\n");

          if (ax_stable)
          {
              debug_print("PATTERN MODE\r\n");
              Haptic_LongWarningPattern(200);
          }
          else
          {
              debug_print("CONTINUOUS MODE\r\n");
              Haptic_PlayForMs(200, 3000);
          }
      }
      else if (radar_state == RADAR_YIPPEE_2)
      {
          debug_print("YIPPEE 2\r\n");

          if (ax_stable)
          {
              debug_print("PATTERN MODE\r\n");
              Haptic_LongWarningPattern(180);
          }
          else
          {
              debug_print("CONTINUOUS MODE\r\n");
              Haptic_PlayForMs(180, 3000);
          }
      }

      HAL_Delay(10);
  }
  /* USER CODE END WHILE */

}

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


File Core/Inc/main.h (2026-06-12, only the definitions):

#define EN1_Pin GPIO_PIN_4
#define EN1_GPIO_Port GPIOA
#define EN2_Pin GPIO_PIN_5
#define EN2_GPIO_Port GPIOA
#define BNO055_RST_Pin GPIO_PIN_6
#define BNO055_RST_GPIO_Port GPIOA
#define RADAR_GPIO_Pin GPIO_PIN_7
#define RADAR_GPIO_GPIO_Port GPIOA

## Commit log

2026-06-12 testing paragraph spacing
    Expanded the README.md to include detailed descriptions of the hardware architecture, power distribution, radar sensor, inertial measurement unit, haptic feedback system, communications and debug int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
2026-06-12 Update README with bike testing process improvements
    Refined testing process details for bike radar system, including adjustments to detection range and velocity thresholds for warnings.
2026-06-12 Challenges and lessons learned
    Added detailed sections on radar configuration, communication challenges, detection threshold tuning, and power management for improved project documentation.
2026-06-12 Fix typo in README.md for 'Drivers' section
2026-06-12 Change wiring diagram image from PNG to JPG
    Updated the wiring diagram image format from PNG to JPG.

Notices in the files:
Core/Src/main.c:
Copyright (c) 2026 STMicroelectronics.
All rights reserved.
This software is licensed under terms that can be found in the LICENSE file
